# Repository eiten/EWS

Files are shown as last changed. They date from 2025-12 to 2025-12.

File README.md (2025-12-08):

# 🔌 Universal Voron Power & CAN HAT (EWS)

> 🌍 **Languages:** [English](README.md) | [Deutsch](README.de.md)

A universal interface board (HAT) for Raspberry Pi 4/5 and Radxa Rock 5B designed for use in Voron 3D printers. Provides powerful 5V supply (8A), CAN-Bus interface (USB-Bridge or Native), and USB hub.

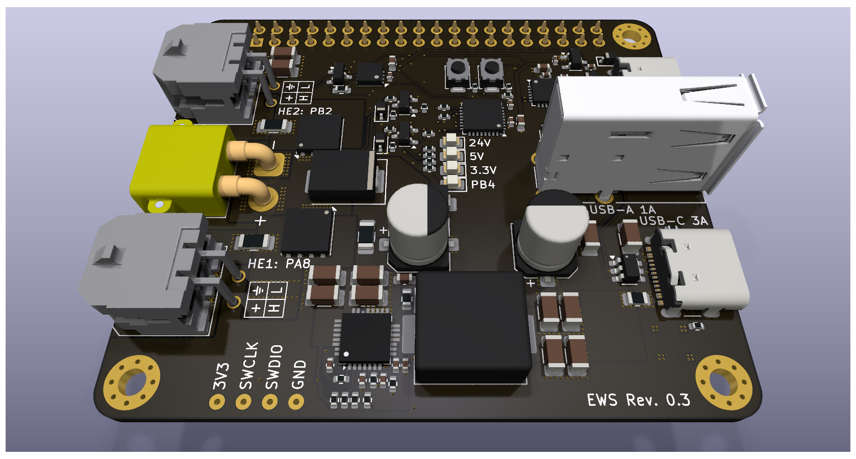
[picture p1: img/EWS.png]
Universal Voron Power & CAN HAT


## 📚 Contents

<!-- @import "[TOC]" {cmd="toc" depthFrom=1 depthTo=6 orderedList=false} -->

<!-- code_chunk_output -->

- [🔌 Universal Voron Power & CAN HAT (EWS)](#-universal-voron-power--can-hat-ews)
  - [📚 Contents](#-contents)
  - [🎯 About EWS](#-about-ews)
  - [🚨 Problems Addressed](#-problems-addressed)
  - [✨ Features](#-features)
    - [🔋 Power Supply (24V Input)](#-power-supply-24v-input)
    - [⚡ DC/DC Converter (5V Output)](#-dcdc-converter-5v-output)
    - [🔌 Logic Power Supply (Power Path)](#-logic-power-supply-power-path)
    - [💻 MCU & CAN Interface](#-mcu--can-interface)
    - [📡 USB Hub](#-usb-hub)
  - [📋 Klipper Configuration](#-klipper-configuration)
    - [Basic MCU Setup](#basic-mcu-setup)
  - [🔌 Pinout & Connector Assignment](#-pinout--connector-assignment)
    - [Power Input](#power-input)
    - [CAN-Bus Ports](#can-bus-ports)
    - [USB Ports](#usb-ports)
  - [🛠️ PCB Specifications](#️-pcb-specifications)
  - [⚠️ Manufacturing Recommendations](#️-manufacturing-recommendations)
    - [PCB Manufacturing](#pcb-manufacturing)
    - [Assembly Notes](#assembly-notes)
    - [Component Sourcing](#component-sourcing)
  - [🛠️ Technical Specifications](#️-technical-specifications)
  - [📚 Additional Resources](#-additional-resources)
  - [📝 Changelog](#-changelog)
  - [License](#license)

<!-- /code_chunk_output -->

## 🎯 About EWS

**EWS** stands for "Eierlegende Wollmilchsau" (German for "egg-laying woolly milk pig") - a humorous term for a universal solution that does everything. This HAT lives up to its nickname by combining multiple essential functions for Voron 3D printer control systems in a single, compact board.

The board addresses common pain points in Voron builds by providing robust power distribution, reliable CAN communication, and convenient USB connectivity while maintaining compatibility with both Raspberry Pi and Radxa Rock 5B single-board computers.

## 🚨 Problems Addressed

This board was designed to solve multiple critical issues commonly encountered in high-performance 3D printer setups:

### ⚡ **Power & Supply Issues**
- **Unstable SBC power supply** - Many setups suffer from voltage drops and power instability
- **Separate power injection required** - USB-C touchscreens often need additional power supplies
- **Power distribution complexity** - Multiple power sources create wiring challenges

### 🔗 **CAN Communication Problems**
- **USB-CAN adapters** - Difficult to mount, unreliable connections, additional failure points
- **Controller board limitations** - Using Spider/Octopus as CAN bridge often has built-in termination resistors
- **CAN topology conflicts** - Can't run both CAN toolheads and ADXL boards simultaneously on many controller boards
- **Native CAN unavailable** - Most SBC setups lack proper native CAN interface utilization

### 🔥 **Safety Concerns**
- **Fire hazard from thermal runaway** - No way to disconnect toolhead power during emergencies
- **Uncontrolled power delivery** - Toolheads remain powered even during faults
- **Limited emergency shutdown** - Difficult to implement comprehensive safety cutoffs

### 🔌 **Wiring & Installation**
- **Complex cable management** - CAN and 24V power start from different locations
- **Multiple connection points** - Increases failure modes and installation complexity
- **Inadequate connector standards** - Mix of different connector types creates confusion

### 🖥️ **USB & Peripheral Issues**
- **Limited USB ports** - SBCs often lack sufficient high-power USB connectivity
- **USB hub limitations** - External hubs add complexity and potential points of failure
- **Power delivery standards** - Inconsistent USB-C power delivery for modern touchscreens

## ✨ Features

### 🔋 Power Supply (24V Input)

- **Input Voltage:** 24V DC nominal
- **Connectors:** XT30PW-F (horizontal) or 5.08mm screw terminal
- **Toolhead Switching:** 2x P-Channel MOSFETs (CJAC70P06, -60V, -70A, RDSon ~8mΩ) controlled by PB2 and PA5 for toolhead power switching (safety feature if PWM-FET on toolhead fails)
- **Overvoltage Protection:** TVS diode (SMAJ26A, 26V Standoff, Unidirectional) to GND
- **Input Protection:** Distributed fusing (5A for DC/DC, 5A each for CAN ports)

### ⚡ DC/DC Converter (5V Output)

- **Controller:** MaxLinear XR76208 (Synchronous Step-Down, 8A, COT)
- **Input Fuse:** 5A SMD 1812 Slow Blow
- **Reverse Polarity Protection:** SS56 Schottky diode
- **Output Voltage:** 5.1V (set via feedback divider: R_Top=15kΩ, R_Bottom=2.0kΩ)
- **Switching Frequency:** ~600kHz (set via Ron=30kOhm)
- **Inductance:** 3.3µH Shielded (Sunlord MDA1050-3R3M, Isat ~17A)
- **Input Capacitors:** 4x 10µF 1206 ceramic + 1x 100µF electrolytic/polymer (bulk)
- **Output Capacitors:** 4x 22µF 1206 ceramic
- **Stability:** Feed-forward capacitor (Cff) 1nF parallel to upper feedback resistor
- **Soft-Start:** 100nF at SS pin (~6ms startup time)
- **Current Limit:** 5.1kΩ resistor (~10.2A limit)
- **Enable:** Voltage divider from 24V (100kΩ upper, 22kΩ lower) = ~4.3V at pin

### 🔌 Logic Power Supply (Power Path)

- **Concept:** Separation of +5V_PWR (high current for screen/webcam) and +5V_LOGIC (for MCU/Hub)
- **Diode OR-ing:** 2x Schottky diodes (1N5819WS, 1A)
  - Source 1: USB_VBUS (from Pi/PC) → Diode → +5V_LOGIC
  - Source 2: +5V_BUCK (from 8A regulator) → Diode → +5V_LOGIC
- **Purpose:** Board is USB-flashable without 24V supply, no backflow to PC
- **3.3V Generation:** LDO (XC6206) powered from +5V_LOGIC

### 🧠 MCU & CAN Interface

- **Microcontroller:** STM32G0B1KBU6 (UFQFPN-32)
- **Clocking:** Crystal-less (Internal HSI48 with Clock Recovery System CRS via USB)
- **Pi Connection:**
  - USB (PA11/PA12) to USB Hub
  - UART (PA9/PA10) to Pi Header (Pin 8/10) via jumperable connection
  - NRST to Pi GPIO 22 (via 1kΩ) + button to GND + 100nF cap
  - BOOT0 (Pin 24/PA14 shared with SWCLK) to Pi GPIO 27 (via 1kΩ) + button to 3.3V + 10kΩ pull-down
- **CAN Transceiver:** MCP2542WFD (or compatible)
- **Muxing:** Jumper selectable between STM32 (USB-CAN Bridge) and Rock/Pi Native GPIOs (Pin 3/5). For ROCK 5B/5B+, jumpers can select whether CAN comes from onboard STM32G0B1 or goes natively to Rockchip (via GPIO header Pin 3 (CAN-RX) and Pin 5 (CAN-TX))
- **Termination:** 120 Ω resistor, switchable per jumper (directly at connectors)
- **CAN Connectors:** 2x Molex Micro-Fit 3.0 (2x2)
- **Micro-Fit Pinout:** Pin 1=24V, Pin 2=GND (upper row), Pin 3=CAN_H, Pin 4=CAN_L (lower row)
- **CAN Power Protection:** 5A SMD 1812 Slow Blow per port

### 📡 USB Hub

- **Controller:** WCH CH334F (QFN-24)
- **Speed:** USB 2.0 High Speed (480 Mbit/s) with MTT
- **Clocking:** Internal (crystal-less), XI/XO pins left open
- **Supply:** V5 to +5V_LOGIC
- **Upstream:** To Raspberry Pi Header (USB loopback cable required) or USB-C input
- **Downstream Ports:**
  - STM32 (internal)
  - USB-C connector (for touchscreen)
  - USB-A connector (vertical, for webcam)

**USB Port Protection:**
- **Concept:** 100µF electrolytic tank at +5V_PWR, followed by polyfuse, followed by 22µF ceramic at connector
- **USB-C Port (Screen):**
  - Polyfuse: 4.0A hold current (hot chamber derating considered)
  - CC Lines: CC1 and CC2 each with 10kΩ resistor to VBUS (behind fuse) for 3A advertisement
  - ESD Protection: SRV05-4 TVS array
- **USB-A Port (Webcam):**
  - Polyfuse: 1.5A hold current
- **ESD Protection:** SRV05-4 TVS array

## 📋 Klipper Configuration

### Basic MCU Setup
```ini
[mcu hat]
canbus_uuid: your_uuid_here
# Alternative for USB connection:
# serial: /dev/serial/by-id/usb-katapult_stm32g0b1xx_your_id-if00

[temperature_sensor hat_mcu]
sensor_type: temperature_mcu
sensor_mcu: hat
```

## 🔌 Pinout & Connector Assignment

### Power Input
- **XT30PW-F (horizontal)** or **5.08mm Screw Terminal**
  - Pin 1: +24V
  - Pin 2: GND

### CAN-Bus Ports
- **2x Molex Micro-Fit 3.0 (2x2, THT)**
  - Pin 1: +24V (upper row, left)
  - Pin 2: GND (upper row, right)
  - Pin 3: CAN_H (lower row, left)
  - Pin 4: CAN_L (lower row, right)

### USB Ports
- **USB-C:** Touchscreen connection (5V/3A capability)
- **USB-A:** Webcam connection (vertical mount)

## 🛠️ PCB Specifications

| Parameter | Specification |
|---|---|
| **Form Factor** | Standard HAT (65mm x 56mm) |
| **Layer Stack** | 4-Layer Multilayer |
| **Layer 1 (Top)** | Signal/Power |
| **Layer 2** | GND Plane |
| **Layer 3** | 5V Power Plane |
| **Layer 4 (Bottom)** | Signal/GND |
| **Solder Mask** | Black Matte |
| **Surface Finish** | ENIG (Gold) |
| **Silkscreen** | White |
| **Mounting** | Inner mounting holes (Pi/Rock compatible) |
| **EMI Design** | Mounting holes via-stitched to GND planes (Layer 2 & Bottom), isolated from 5V plane (Layer 3) |

## ⚠️ Manufacturing Recommendations

### PCB Manufacturing
- **Copper Weight:** **2oz copper recommended** for improved thermal performance and current handling
- **Via Specifications:** Minimum 12-20 vias at DC/DC PGND for thermal management
- **Impedance Control:** 90 Ω differential for USB traces (D+/D- pairs)

### Assembly Notes
- **24V Path:** Minimum 3mm trace width on top & bottom layers for 12A total current
- **5V Distribution:** Use Layer 3 plane with solid connections (no thermals) to headers and capacitors
- **Thermal Management:** QFN GND pads connected with vias, considering bottom layer routing

### Component Sourcing
- Ensure polyfuse derating for chamber temperatures up to 60°C
- Select inductors with sufficient saturation current (>15A recommended)
- Use low-ESR capacitors for switching regulator

## 🛠️ Technical Specifications

| Parameter | Value | Unit |
|---|---|---|
| **Input Voltage** | 24 ± 2 | V |
| **5V Output Current** | 8 | A |
| **Logic Supply Current** | 2 | A |
| **CAN Baud Rate** | up to 1 | Mbit/s |
| **USB Speed** | 480 | Mbit/s |
| **Operating Temperature** | -10 to +70 | °C |
| **Dimensions** | 65 x 56 | mm |

## 📚 Additional Resources

- [Klipper Documentation](https://www.klipper3d.org/Config_Reference.html)
- [CAN-Bus Setup Guide](https://www.klipper3d.org/CANBUS.html)
- [Voron Documentation](https://docs.vorondesign.com/)
- [STM32G0 Reference Manual](https://www.st.com/resource/en/reference_manual/rm0454-stm32g0x0-advanced-armbased-32bit-mcus-stmicroelectronics.pdf)
- [Katapult Firmware Flasher](https://github.com/Arksine/katapult)

## 📝 Changelog

For detailed information about changes and updates, see [CHANGELOG.md](CHANGELOG.md).

## License

This project is licensed under the **Creative Commons Attribution-NonCommercial-ShareAlike 4.0 International License** (CC BY-NC-SA 4.0).



This means you are free to:
- **Share** — copy and redistribute the material in any medium or format
- **Adapt** — remix, transform, and build upon the material

Under the following terms:
- **Attribution** — You must give appropriate credit, provide a link to the license, and indicate if changes were made
- **NonCommercial** — You may not use the material for commercial purposes
- **ShareAlike** — If you remix, transform, or build upon the material, you must distribute your contributions under the same license

For the full license text, visit: https://creativecommons.org/licenses/by-nc-sa/4.0/

---

> **Note:** The original documentation is in German ([README.de.md](README.de.md)). This English version is a translation for international users.

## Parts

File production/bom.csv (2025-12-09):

Designator | Footprint | Quantity | Value | LCSC Part #
C201, C403 | CP_Elec_6.3x7.7 | 2 | 100u | C3151829
C202, C204, C205, C206 | 1206 | 4 | 10u | C13585
C203, C207, C211 | 0402 | 3 | 1u | C52923
C208, C210, C301, C302, C305, C401, C404 | 0402 | 7 | 100n | C307331
C209 | 0402 | 1 | 4u7 | C23733
C212 | 0603 | 1 | 220p | C1603
C213 | 0402 | 1 | 1n | C1523
C214, C215, C216, C217, C306, C307, C405, C406 | 1206 | 8 | 22u | C12891
C303, C304, C402 | 0603 | 3 | 10u | C96446
D201, D202, D203 | 0805 | 3 | YELLOW | C2296
D301 | 0805 | 1 | GREEN | C2297
D302 | SOT-23 | 1 | PESD1CAN | C907838
D401, D402 | D_SOD-323 | 2 | BZT52C15S | C19077448
D403 | D_SMC | 1 | SS56 | C24138
D404 | D_SMA | 1 | SMAJ26A | C19077543
D405, D406 | D_SOD-323 | 2 | 1N5819WS | C191023
F201 | 1206 | 1 | 3A | C163126
F401, F402 | 1206 | 2 | 5A | C163128
F403 | 0805 | 1 | 4A | C2680546
F404 | 0805 | 1 | 1.5A | C914095
HS201 | HeatSink_9x9x5 | 1 | Heatsink
J301 | PinSocket_2x20_P2.54mm_Vertical | 1 | GPIO
J401 | AMASS_XT30PW-M_1x02_P2.50mm_Horizontal | 1 | XT30 | C431092
J402, J403 | Molex_Micro-Fit_3.0_43045-0400_2x02_P3.00mm_Horizontal | 2 | MX3.0 2x2 | C122413
J404, J405 | USB_C_Receptacle_GCT_USB4105-xx-A_16P_TopMnt_Horizontal | 2 | USB-C | C2765186
J406 | USB_A_Wuerth_614004134726_Horizontal | 1 | USB-A | C18077685
L201 | L_APV_APH1050 | 1 | 3.3uH | C2847560
Q401, Q402 | AO_DFN-8-1EP_5.55x5.2mm_P1.27mm_EP4.12x4.6mm | 2 | CJAC70P06 | C2898279
Q403, Q404 | SOT-23 | 2 | AO3400A | C20917
R201 | 0402 | 1 | 22k | C25768
R202, R205 | 0402 | 2 | 2k2 | C25879
R203, R302, R305, R407, R408 | 0402 | 5 | 1k | C11702
R204 | 0402 | 1 | 100k | C25741
R206, R303, R411, R412 | 0402 | 4 | 10k | C25744
R207, R401, R402, R403, R404, R405, R406 | 0402 | 7 | 33k | C25779
R208, R409, R410 | 0402 | 3 | 5k1 | C25905
R209 | 0603 | 1 | 1R | C22936
R210 | 0402 | 1 | 15k | C25756
R211 | 0402 | 1 | 2k | C4109
R301 | 0402 | 1 | 330R | C25104
R304 | 0603 | 1 | 120R | C22787
SW301, SW302 | SW_SPST_TS-1088-xR020 | 2 | TS-1088 | C720477
U201 | SOT-23-3 | 1 | XC6206P332MR | C5446
U202 | IC_XR76208ELTR-F | 1 | XR76208 | C555356
U301 | HVSON-8-1EP_3x3mm_P0.65mm_EP1.6x2.4mm | 1 | TJA1051TK-3 | C2875699
U302 | QFN-32-1EP_5x5mm_P0.5mm_EP3.45x3.45mm | 1 | STM32G0B1KBUx | C5159549
U401 | QFN-24-1EP_4x4mm_P0.5mm_EP2.7x2.7mm_ThermalVias | 1 | CH334F | C5187527
U402, U403, U404 | SOT-23-6 | 3 | USBLC6-2SC6 | C2687116

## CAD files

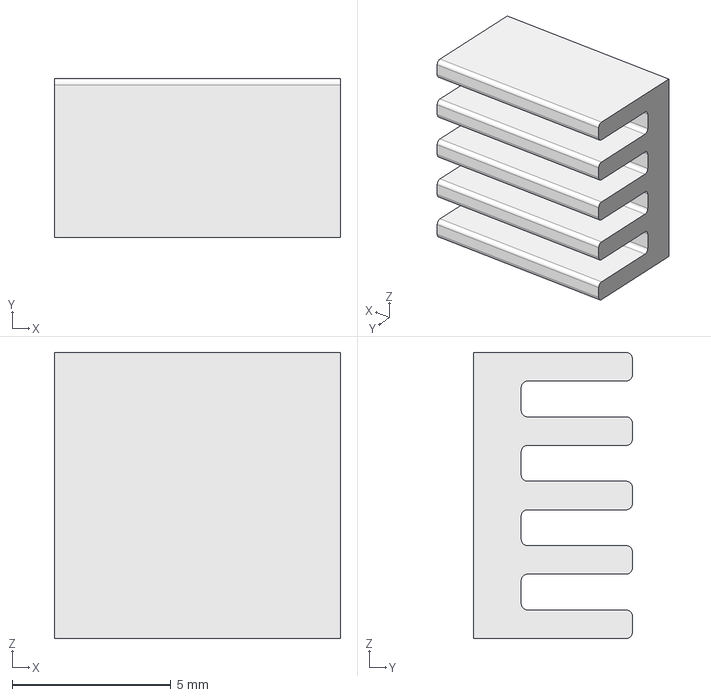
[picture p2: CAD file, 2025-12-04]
3d/9x9x5.step
9.00 x 5.00 x 9.00 mm

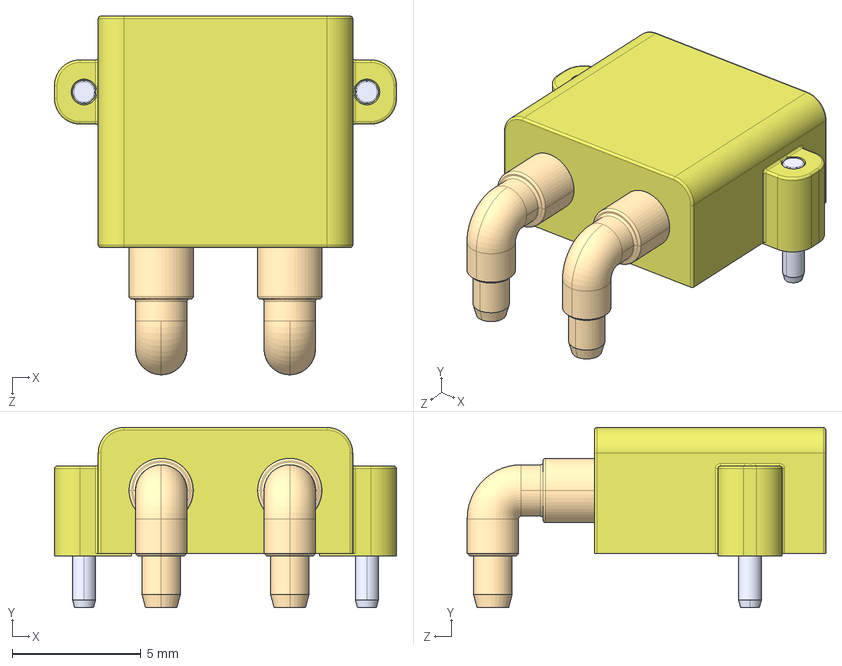
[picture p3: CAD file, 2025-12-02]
3d/XT30PW-M--3DModel-STEP-269445.STEP
13.3 x 7.00 x 14.0 mm

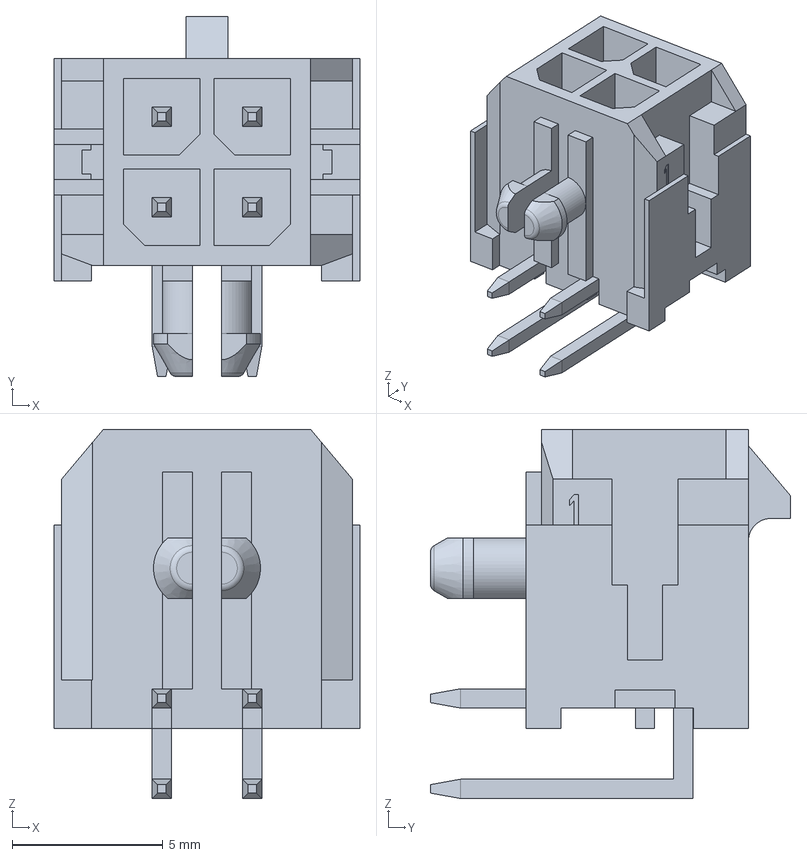
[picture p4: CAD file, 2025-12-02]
3d/430450400.stp
10.2 x 11.9 x 12.2 mm

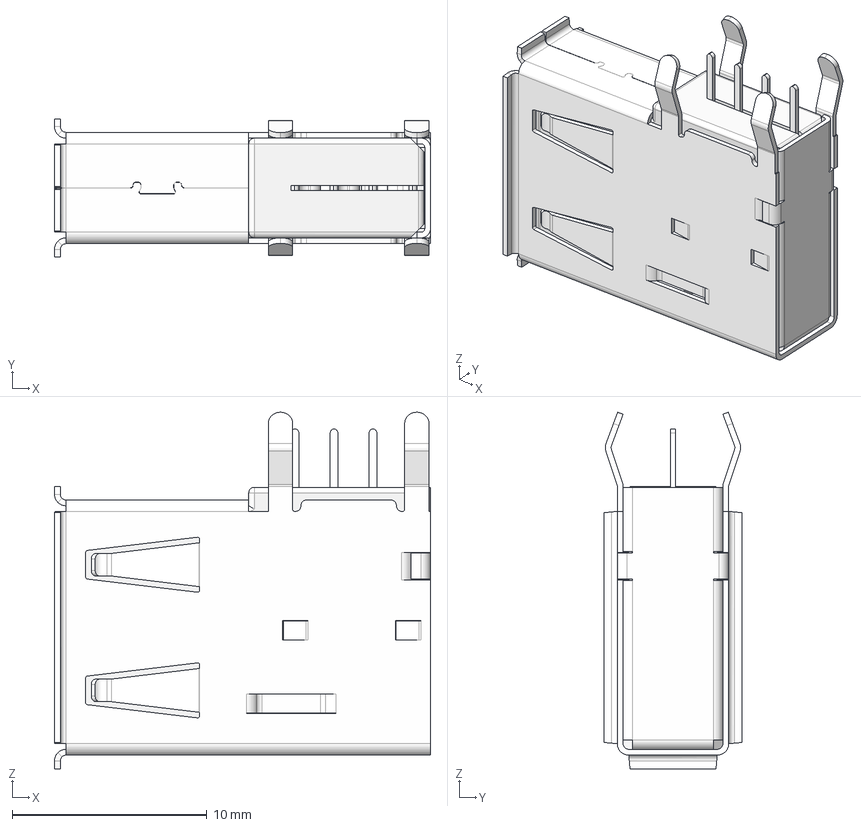
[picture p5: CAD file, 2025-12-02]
3d/614004134726.stp
19.3 x 7.10 x 18.3 mm
Blech
Blech_Deckel
Pin_4
Gehäuse_Pin
Pin_3
Pin_2
Pin_1

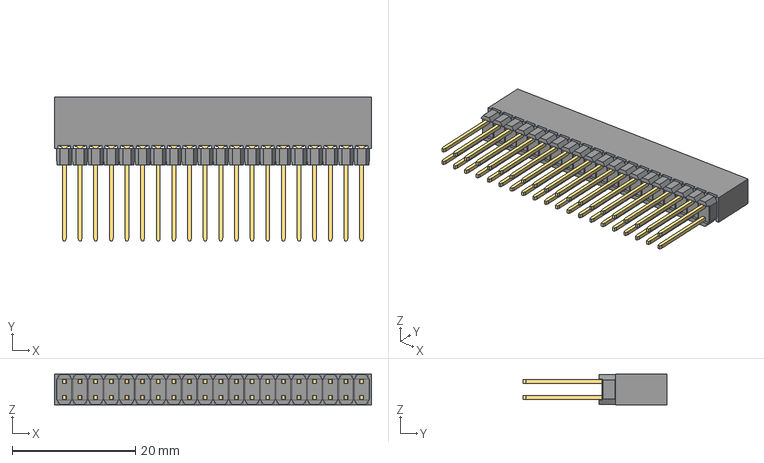
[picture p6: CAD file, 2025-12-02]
3d/m20-6102045.stp
51.5 x 23.4 x 5.00 mm

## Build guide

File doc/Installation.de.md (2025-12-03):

# 🛠️ EWS Installation Guide

> 🌍 **Sprachen:** [English](Installation.en.md) | [Deutsch](Installation.de.md)

Ein umfassender Leitfaden zur Installation des Device Tree Overlays und der Kernelmodule für das Universal Voron Power & CAN HAT (EWS).

## 📚 Inhaltsverzeichnis

- [🛠️ EWS Installation Guide](#️-ews-installation-guide)
  - [📚 Inhaltsverzeichnis](#-inhaltsverzeichnis)
  - [🏔️ Radxa Rock OS](#️-radxa-rock-os)
    - [🔍 Kernel-Treiber Diagnose](#-kernel-treiber-diagnose)
    - [📄 Device Tree Setup (DTS)](#-device-tree-setup-dts)
  - [⚠️ Wichtige Hinweise](#️-wichtige-hinweise)

## 🏔️ Radxa Rock OS

Beim Rock OS variiert die CAN-Unterstützung von Version zu Version. Eine sorgfältige Diagnose ist daher vor der Installation erforderlich.

### 🔍 Kernel-Treiber Diagnose

#### Schritt 1: Verfügbare Module prüfen
Zuerst überprüfen wir, ob die erforderlichen Kernelmodule vorhanden sind:

```bash
find /lib/modules/$(uname -r)/kernel/drivers/net/can -name "*.ko*"
```

Sind in der Liste Dateien mit Namen enthalten, die `rockchip_canfd` oder `m_can` enthalten, sind die Module vorhanden und alles sollte funktionieren.

#### Schritt 2: Kernel-Konfiguration überprüfen
Falls keine Module gefunden wurden, prüfen wir die Kernel-Konfiguration:

```bash
grep -E "CONFIG_CAN_ROCKCHIP|CONFIG_CAN_FD" /boot/config-$(uname -r)
```

#### 🚦 Diagnose-Ergebnisse

##### ✅ Fall A: `CONFIG_CAN_ROCKCHIP=y`
- **Status:** ✅ OK
- **Bedeutung:** Der Treiber ist fest im Kernel integriert
- **Hinweis:** Erscheint NICHT unter `lsmod` und hat keine `.ko` Datei
- **Aktion:** Das Overlay reicht zur Aktivierung

##### ⚠️ Fall B: `CONFIG_CAN_ROCKCHIP=m`
- **Status:** ⚠️ Prüfung erforderlich
- **Bedeutung:** Der Treiber ist ein ladbares Modul
- **Prüfung:** Modul-Datei suchen:
  ```bash
  find /lib/modules/$(uname -r) -name "rockchip_canfd.ko*"
  ```
- **Falls Datei fehlt:** Kernel-Pakete reinstallieren:
  ```bash
  sudo apt install --reinstall linux-image-rk3588*
  ```

##### ❌ Fall C: `# CONFIG_CAN_ROCKCHIP is not set`
- **Status:** ❌ KRITISCHER FEHLER
- **Symptom:** Ausgabe enthält `# CONFIG_CAN_ROCKCHIP is not set` und meist auch `# CONFIG_CAN_M_CAN is not set`
- **Bedeutung:** Kernel wurde ohne CAN-Controller-Unterstützung kompiliert
- **Problem:** Der Treiber fehlt komplett
- **DKMS-Option:** ⚠️ Praktisch unmöglich bei SoC-internen Treibern
- **Lösung:** 🔄 Zwingender Wechsel des Betriebssystems/Kernels (z.B. Armbian Vendor Kernel)

### 📄 Device Tree Setup (DTS)

Nach erfolgreicher Kernel-Diagnose kann das CAN-Overlay installiert werden:

#### Installation über Radxa Setup-Tool

1. **📁 Verzeichnis wechseln**
   ```bash
   cd dts
   ```

2. **🛠️ Radxa Setup starten**
   ```bash
   sudo rsetup
   ```

3. **🧭 Navigation im Setup-Menü**
   - Navigiere zu `Overlays` ➜ `Install 3rd party overlay`

4. **📋 Overlay auswählen**
   - Wähle `rk3588-can1-m1.dts` aus der Liste

5. **🔄 System neustarten**
   ```bash
   sudo reboot
   ```

#### ✅ Installation verifizieren

Nach dem Neustart sollte die CAN-Schnittstelle verfügbar sein:

```bash
ip link show can1
```

**Erwartete Ausgabe:**
```
3: can1: <NOARP> mtu 72 qdisc noop state DOWN mode DEFAULT group default qlen 10
    link/can
```

## ⚠️ Wichtige Hinweise

- 🔧 **Jumper-Einstellungen:** Stelle sicher, dass alle Jumper auf dem EWS-Board korrekt gesetzt sind
- 🚨 **Neustart erforderlich:** Das System muss nach der Overlay-Installation neu gestartet werden
- 📋 **Interface-Name:** Die CAN-Schnittstelle wird als `can1` im System verfügbar sein
- 🔌 **Verkabelung:** Überprüfe alle Verbindungen vor der ersten Inbetriebnahme
- 🏔️ **OS-Kompatibilität:** Diese Anleitung bezieht sich speziell auf Radxa Rock OS

---

> **💡 Tipp:** Bei persistenten Problemen empfiehlt sich der Wechsel zu Armbian mit Vendor Kernel für bessere CAN-Unterstützung.

> **Hinweis:** Dies ist die Originaldokumentation in deutscher Sprache. Eine englische Übersetzung finden Sie in [Installation.en.md](Installation.en.md).

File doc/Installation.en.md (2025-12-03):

# 🛠️ EWS Installation Guide

> 🌍 **Languages:** [English](Installation.en.md) | [Deutsch](Installation.de.md)

A comprehensive guide for installing the Device Tree Overlay and kernel modules for the Universal Voron Power & CAN HAT (EWS).

## 📚 Table of Contents

- [🛠️ EWS Installation Guide](#️-ews-installation-guide)
  - [📚 Table of Contents](#-table-of-contents)
  - [🏔️ Radxa Rock OS](#️-radxa-rock-os)
    - [🔍 Kernel Driver Diagnosis](#-kernel-driver-diagnosis)
    - [📄 Device Tree Setup (DTS)](#-device-tree-setup-dts)
  - [⚠️ Important Notes](#️-important-notes)

## 🏔️ Radxa Rock OS

CAN support in Rock OS varies from version to version. Careful diagnosis is therefore required before installation.

### 🔍 Kernel Driver Diagnosis

#### Step 1: Check Available Modules
First, we check if the required kernel modules are present:

```bash
find /lib/modules/$(uname -r)/kernel/drivers/net/can -name "*.ko*"
```

If the list contains files with names that include `rockchip_canfd` or `m_can`, the modules are present and everything should work.

#### Step 2: Check Kernel Configuration
If no modules were found, we check the kernel configuration:

```bash
grep -E "CONFIG_CAN_ROCKCHIP|CONFIG_CAN_FD" /boot/config-$(uname -r)
```

#### 🚦 Diagnosis Results

##### ✅ Case A: `CONFIG_CAN_ROCKCHIP=y`
- **Status:** ✅ OK
- **Meaning:** The driver is built into the kernel
- **Note:** Does NOT appear under `lsmod` and has no `.ko` file
- **Action:** The overlay is sufficient for activation

##### ⚠️ Case B: `CONFIG_CAN_ROCKCHIP=m`
- **Status:** ⚠️ Check required
- **Meaning:** The driver is a loadable module
- **Check:** Search for module file:
  ```bash
  find /lib/modules/$(uname -r) -name "rockchip_canfd.ko*"
  ```
- **If file missing:** Reinstall kernel packages:
  ```bash
  sudo apt install --reinstall linux-image-rk3588*
  ```

##### ❌ Case C: `# CONFIG_CAN_ROCKCHIP is not set`
- **Status:** ❌ CRITICAL ERROR
- **Symptom:** Output contains `# CONFIG_CAN_ROCKCHIP is not set` and usually also `# CONFIG_CAN_M_CAN is not set`
- **Meaning:** Kernel was compiled without CAN controller support
- **Problem:** The driver is completely missing
- **DKMS Option:** ⚠️ Practically impossible with SoC-internal drivers
- **Solution:** 🔄 Mandatory change of operating system/kernel (e.g. Armbian Vendor Kernel)

### 📄 Device Tree Setup (DTS)

After successful kernel diagnosis, the CAN overlay can be installed:

#### Installation via Radxa Setup Tool

1. **📁 Change Directory**
   ```bash
   cd dts
   ```

2. **🛠️ Start Radxa Setup**
   ```bash
   sudo rsetup
   ```

3. **🧭 Navigation in Setup Menu**
   - Navigate to `Overlays` ➜ `Install 3rd party overlay`

4. **📋 Select Overlay**
   - Choose `rk3588-can1-m1.dts` from the list

5. **🔄 Restart System**
   ```bash
   sudo reboot
   ```

#### ✅ Verify Installation

After reboot, the CAN interface should be available:

```bash
ip link show can1
```

**Expected Output:**
```
3: can1: <NOARP> mtu 72 qdisc noop state DOWN mode DEFAULT group default qlen 10
    link/can
```

## ⚠️ Important Notes

- 🔧 **Jumper Settings:** Ensure all jumpers on the EWS board are set correctly
- 🚨 **Reboot Required:** The system must be restarted after overlay installation
- 📋 **Interface Name:** The CAN interface will be available as `can1` in the system
- 🔌 **Wiring:** Check all connections before first operation
- 🏔️ **OS Compatibility:** This guide specifically refers to Radxa Rock OS

---

> **💡 Tip:** For persistent problems, switching to Armbian with Vendor Kernel is recommended for better CAN support.

> **Note:** The original documentation is in German ([Installation.de.md](Installation.de.md)). This English version is a translation for international users.

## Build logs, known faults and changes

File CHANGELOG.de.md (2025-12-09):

# Changelog

> 🌍 **Sprachen:** [English](CHANGELOG.md) | [Deutsch](CHANGELOG.de.md)

Alle wichtigen Änderungen an diesem Projekt werden in dieser Datei dokumentiert.

Das Format basiert auf [Keep a Changelog](https://keepachangelog.com/de/1.0.0/),
und dieses Projekt folgt [Semantic Versioning](https://semver.org/lang/de/).

## [Unreleased]

### Geändert
- **Produktion:** Testpunkte TP202/TP203 von Stückliste ausgeschlossen
- **JLCPCB Optimierung:** Rotations-Offsets für automatische Bestückung angepasst
  - U202/U301: FT Rotation Offset 270°
  - U401: FT Rotation Offset 180°

### Technische Details
- **Fertigungseffizienz:** Optimierte Bauteil-Orientierung reduziert Produktionszeit

## [Rev. 0.3] - 2025-12-09

### Hinzugefügt
- **CAN-Transceiver:** 10µF Kondensator C304 für verbesserte Stabilität der CAN-Kommunikation
- **PCB Layout:** QR Code Platzhalter für Seriennummer auf der Platine

### Technische Details
- **Verbesserte Signal-Integrität:** Zusätzliche Filterung am CAN-Transceiver für stabilere Datenübertragung
- **Rückverfolgbarkeit:** QR Code ermöglicht eindeutige Identifikation und Dokumentation

## [Rev. 0.2] - 2025-12-08

### Verbesserungen
- **Schaltplan:** Aufgeräumt und strukturiert (Dank an "shx")
- **CAN-Transceiver:** Silent Pin auf GND gelegt für bessere Stabilität (Dank an "shx")

### Hinzugefügt
- **Status-LEDs:** 
  - Gelbe LEDs für 24V, 5V und 3.3V Spannungsanzeige
  - Grüne LED am Mikrocontroller (Pin PB4)
- **Solder Jumper:** Ersatz der Standard-Jumper durch Solder Jumper auf der Unterseite
- **PFET-Steuerung:** Jumper für Ausgangs-PFETs hinzugefügt - ermöglicht Dauer-Ein ohne Firmware
- **Testpunkte:** Robuste Testpunkte für 5V und GND für Lasttests eingefügt
- **Heatsink:** Optionaler Heatsink für DC/DC-Wandler auf der Unterseite
- **MCU-Kondensator:** 10µF Kondensator für Mikrocontroller an der 3.3V-Schiene

### Geändert
- **Produktion:** Alle LCSC-Bestellnummern eingefügt, Rotationen definiert, Produktionsdaten erstellt
- **PCB Layout:** 
  - Entsprechend der Schaltplanänderungen angepasst
  - Taster besser positioniert
- **BOM optimiert:**
  - 30kΩ durch Basic-Part 33kΩ ersetzt
  - 15.5kΩ am DC/DC-Feedback durch 15kΩ ersetzt → neue Ausgangsspannung: 5.1V
- **CAN-ESD-Schutz:** NUP2105L durch PESD1CAN ersetzt (bessere Eignung)
- **CAN-Abschlusswiderstand:** Bauform von 0402 auf 0603 geändert für ausreichende Leistung
- **USB-Hub:** Speisung von 5V auf 3.3V umgestellt (gemäß Datenblatt-Empfehlung)

### Technische Details
- **DC/DC-Ausgang:** Neue Spannung 5.1V statt 5.25V durch Feedback-Widerstand-Änderung
- **Verbesserte Wärmeableitung:** Optionaler Heatsink auf Unterseite
- **Stabilere CAN-Kommunikation:** Durch ESD-Schutz-Upgrade und Widerstand-Optimierung

---

> **Hinweis:** Dies ist die Originaldokumentation in deutscher Sprache. Eine englische Übersetzung finden Sie in [CHANGELOG.md](CHANGELOG.md).

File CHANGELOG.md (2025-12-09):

# Changelog

> 🌍 **Languages:** [English](CHANGELOG.md) | [Deutsch](CHANGELOG.de.md)

All notable changes to this project will be documented in this file.

The format is based on [Keep a Changelog](https://keepachangelog.com/en/1.0.0/),
and this project adheres to [Semantic Versioning](https://semver.org/).

## [Unreleased]

### Changed
- **Production:** Test points TP202/TP203 excluded from BOM
- **JLCPCB Optimization:** Rotation offsets adjusted for automated assembly
  - U202/U301: FT Rotation Offset 270°
  - U401: FT Rotation Offset 180°

### Technical Details
- **Manufacturing Efficiency:** Optimized component orientation reduces production time

## [Rev. 0.3] - 2025-12-09

### Added
- **CAN Transceiver:** 10µF capacitor C304 for improved CAN communication stability
- **PCB Layout:** QR code placeholder for serial number on the PCB

### Technical Details
- **Enhanced Signal Integrity:** Additional filtering at CAN transceiver for more stable data transmission
- **Traceability:** QR code enables unique identification and documentation

## [Rev. 0.2] - 2025-12-08

### Improvements
- **Schematic:** Cleaned up and structured (Thanks to "shx")
- **CAN Transceiver:** Silent pin connected to GND for better stability (Thanks to "shx")

### Added
- **Status LEDs:** 
  - Yellow LEDs for 24V, 5V and 3.3V voltage indication
  - Green LED on microcontroller (Pin PB4)
- **Solder Jumpers:** Replaced standard jumpers with solder jumpers on bottom side
- **PFET Control:** Added jumpers for output PFETs - enables permanent-on without firmware
- **Test Points:** Added robust test points for 5V and GND for load testing
- **Heatsink:** Optional heatsink for DC/DC converter on bottom side
- **MCU Capacitor:** 10µF capacitor for microcontroller on 3.3V rail

### Changed
- **Production:** Added all LCSC part numbers, defined rotations, created production data
- **PCB Layout:** 
  - Adjusted according to schematic changes
  - Improved button positioning
- **BOM Optimized:**
  - Replaced 30kΩ with basic part 33kΩ
  - Changed 15.5kΩ DC/DC feedback to 15kΩ → new output voltage: 5.1V
- **CAN ESD Protection:** Replaced NUP2105L with PESD1CAN (better suited)
- **CAN Termination Resistor:** Changed footprint from 0402 to 0603 for adequate power rating
- **USB Hub:** Changed supply from 5V to 3.3V (per datasheet recommendation)

### Technical Details
- **DC/DC Output:** New voltage 5.1V instead of 5.25V due to feedback resistor change
- **Improved Heat Dissipation:** Optional heatsink on bottom side
- **Stable CAN Communication:** Through ESD protection upgrade and resistor optimization

---

> **Note:** The original documentation is in German ([CHANGELOG.de.md](CHANGELOG.de.md)). This English version is a translation for international users.

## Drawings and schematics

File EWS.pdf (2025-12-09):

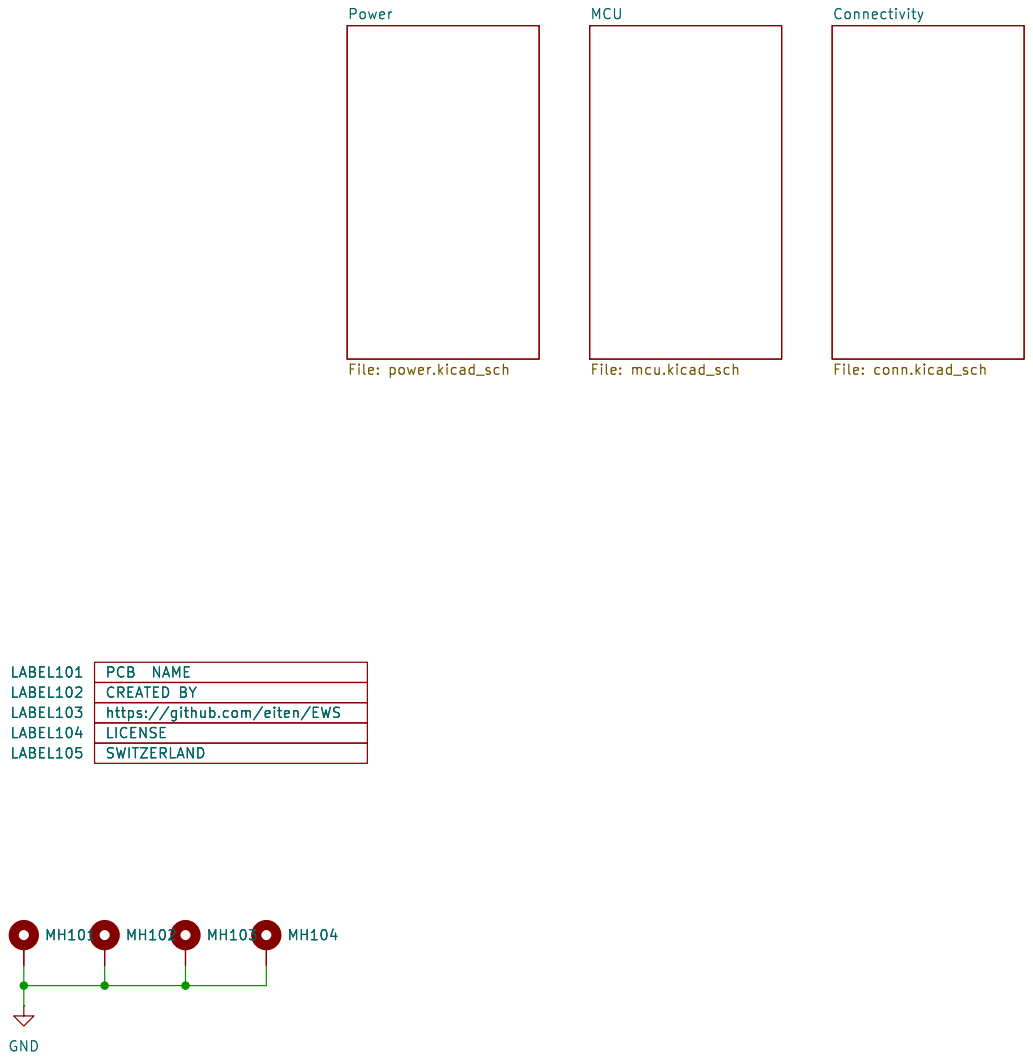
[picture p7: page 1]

Id: 1/4 Title: EWS - Power, CANbus and USB HAT for 3D Printers

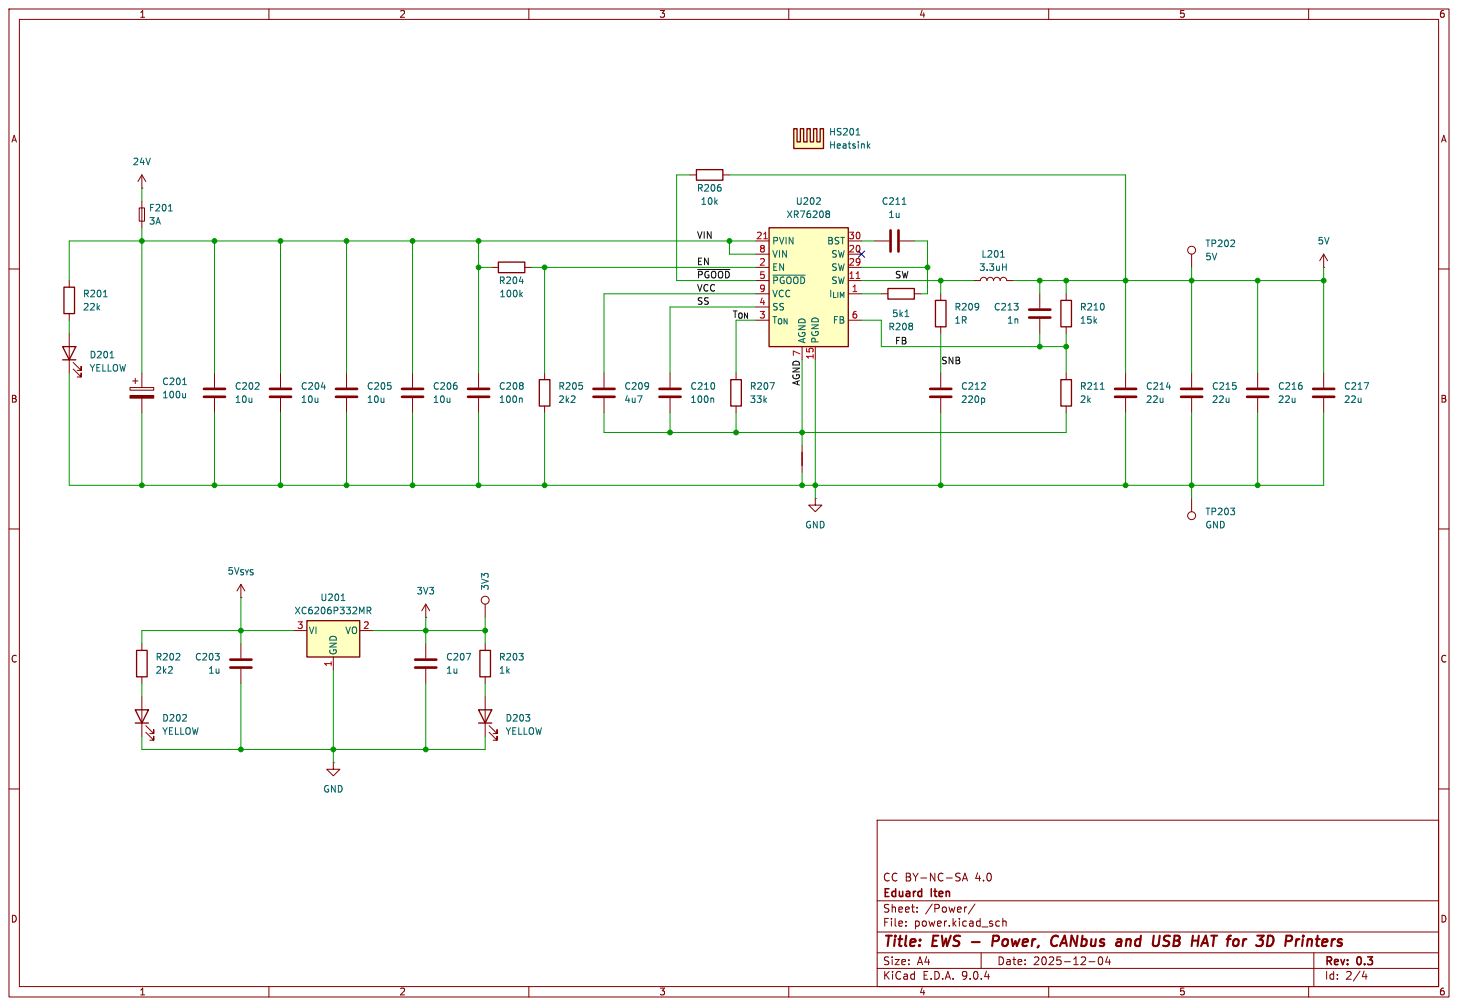
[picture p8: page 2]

7 PGND 15 BST 30 SW 20 SW 29 SW 11

Id: 2/4 Title: EWS - Power, CANbus and USB HAT for 3D Printers

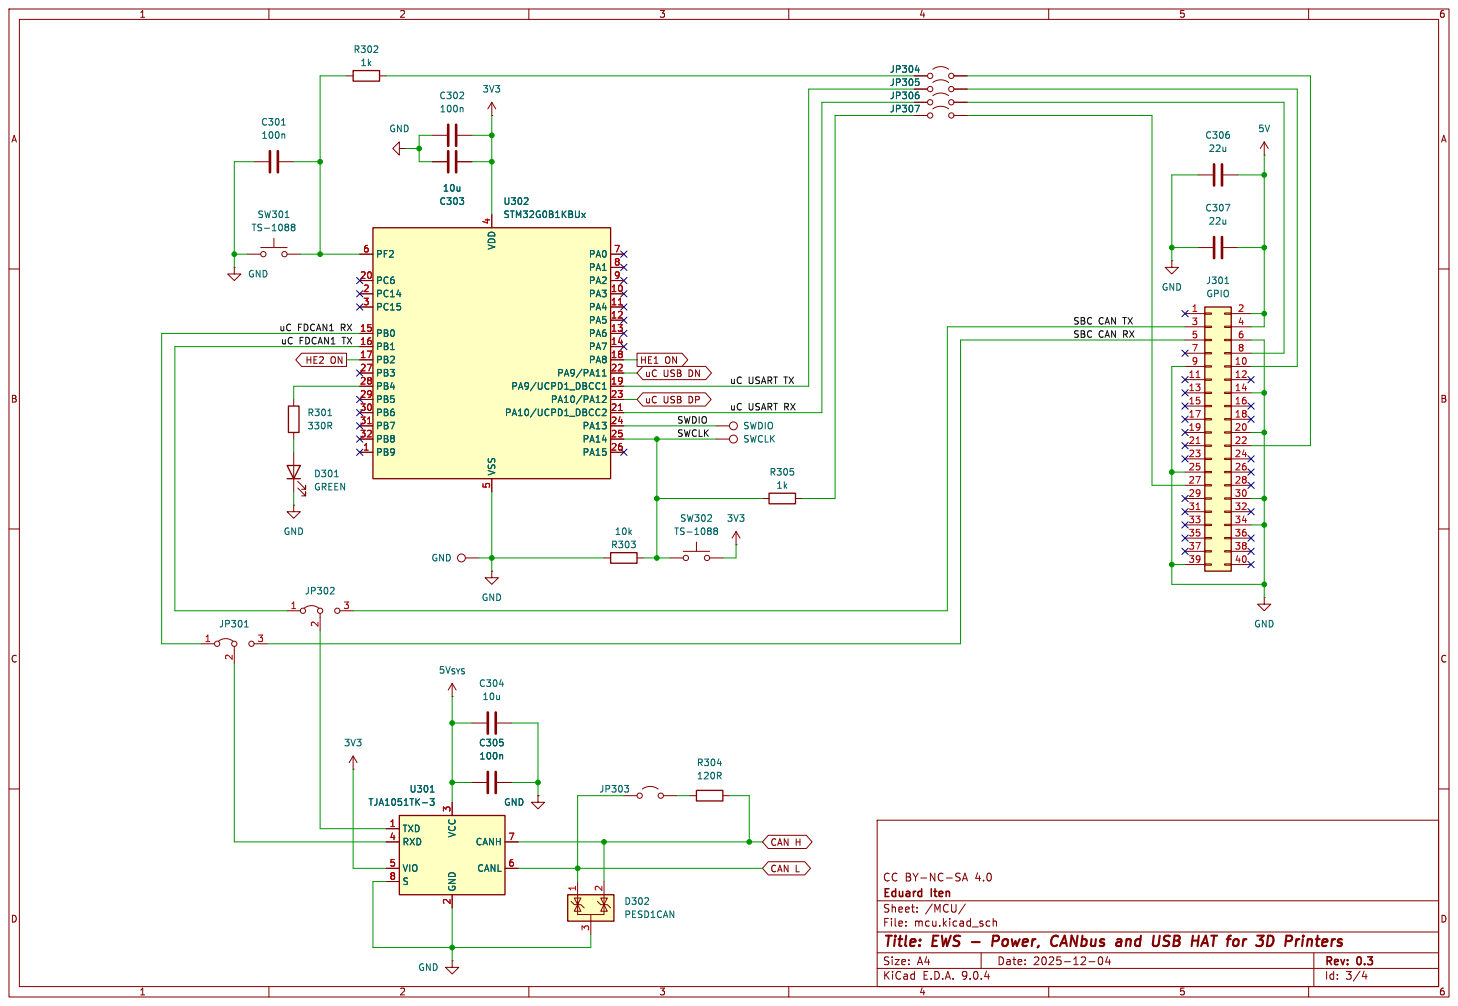
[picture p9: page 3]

Id: 3/4 Title: EWS - Power, CANbus and USB HAT for 3D Printers

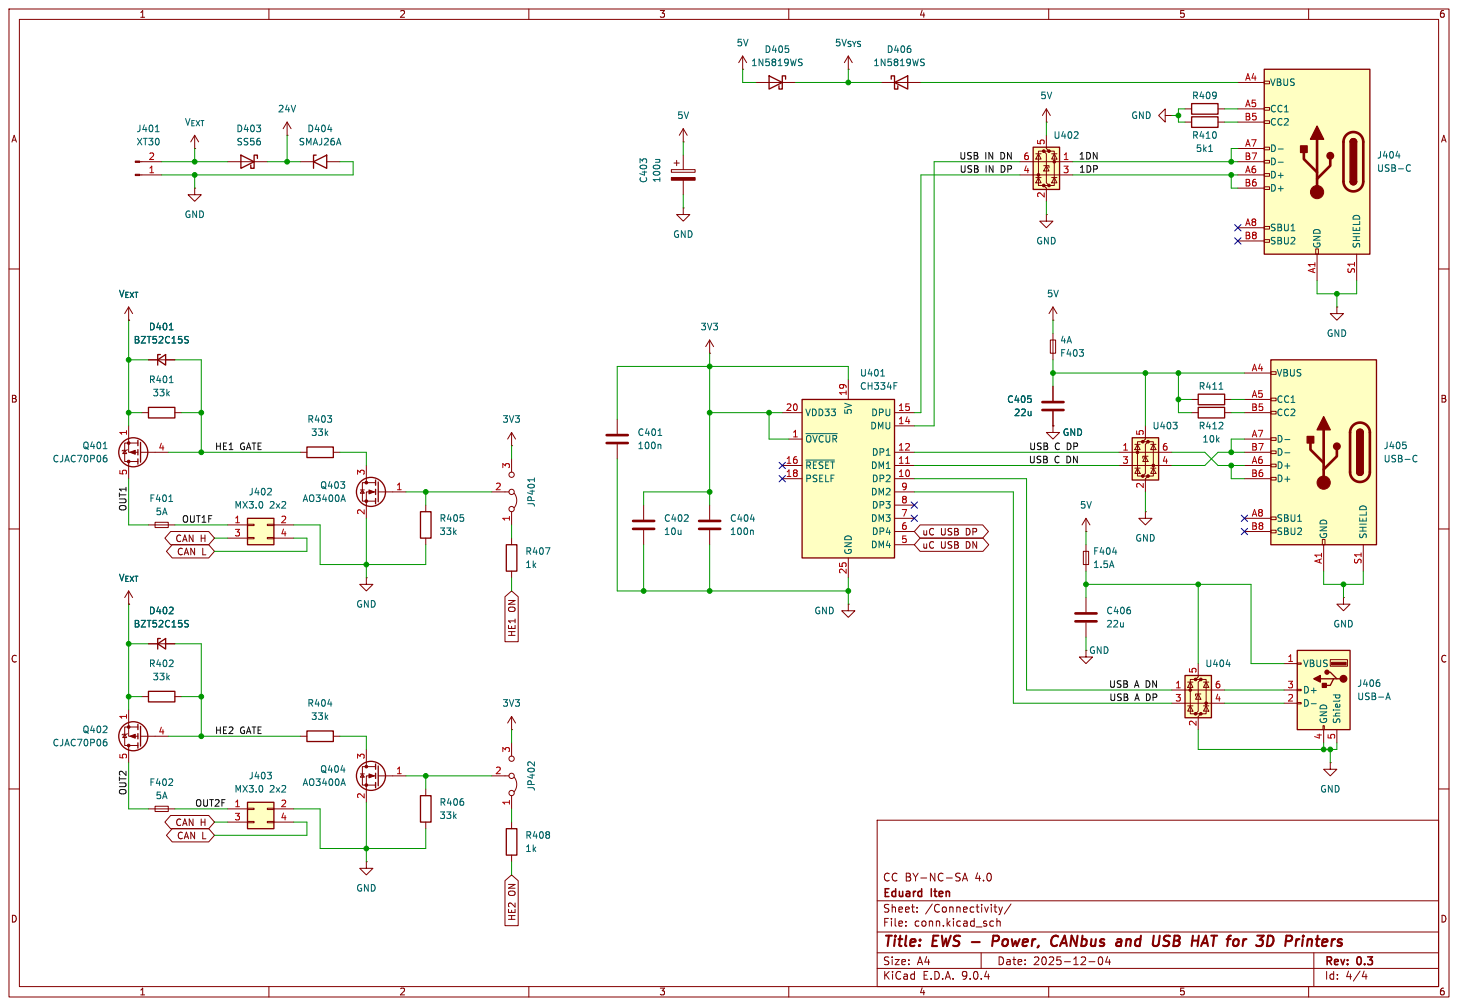
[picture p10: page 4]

5 1 Q401 CJAC70P06 VDD33 20 ~{RESET} 16 PSELF 18 ~{OVCUR} 1 5V 19 GND 25 DPU 15 DMU 14 DP1 12 DM1 11 DP2 10 DM2 9 DP3 8 DM3 7 DP4 6 DM4 5 U401 CH334F GND SHIELD S1 GND A1 VBUS A4 CC1 A5 CC2 B5 D- A7 D- B7 D+ A6 D+ B6 SBU1 A8 SBU2 B8
J403 MX3.0 2x2 CAN H
CAN L

uC USB DN HE2 ON

Id: 4/4 Title: EWS - Power, CANbus and USB HAT for 3D Printers

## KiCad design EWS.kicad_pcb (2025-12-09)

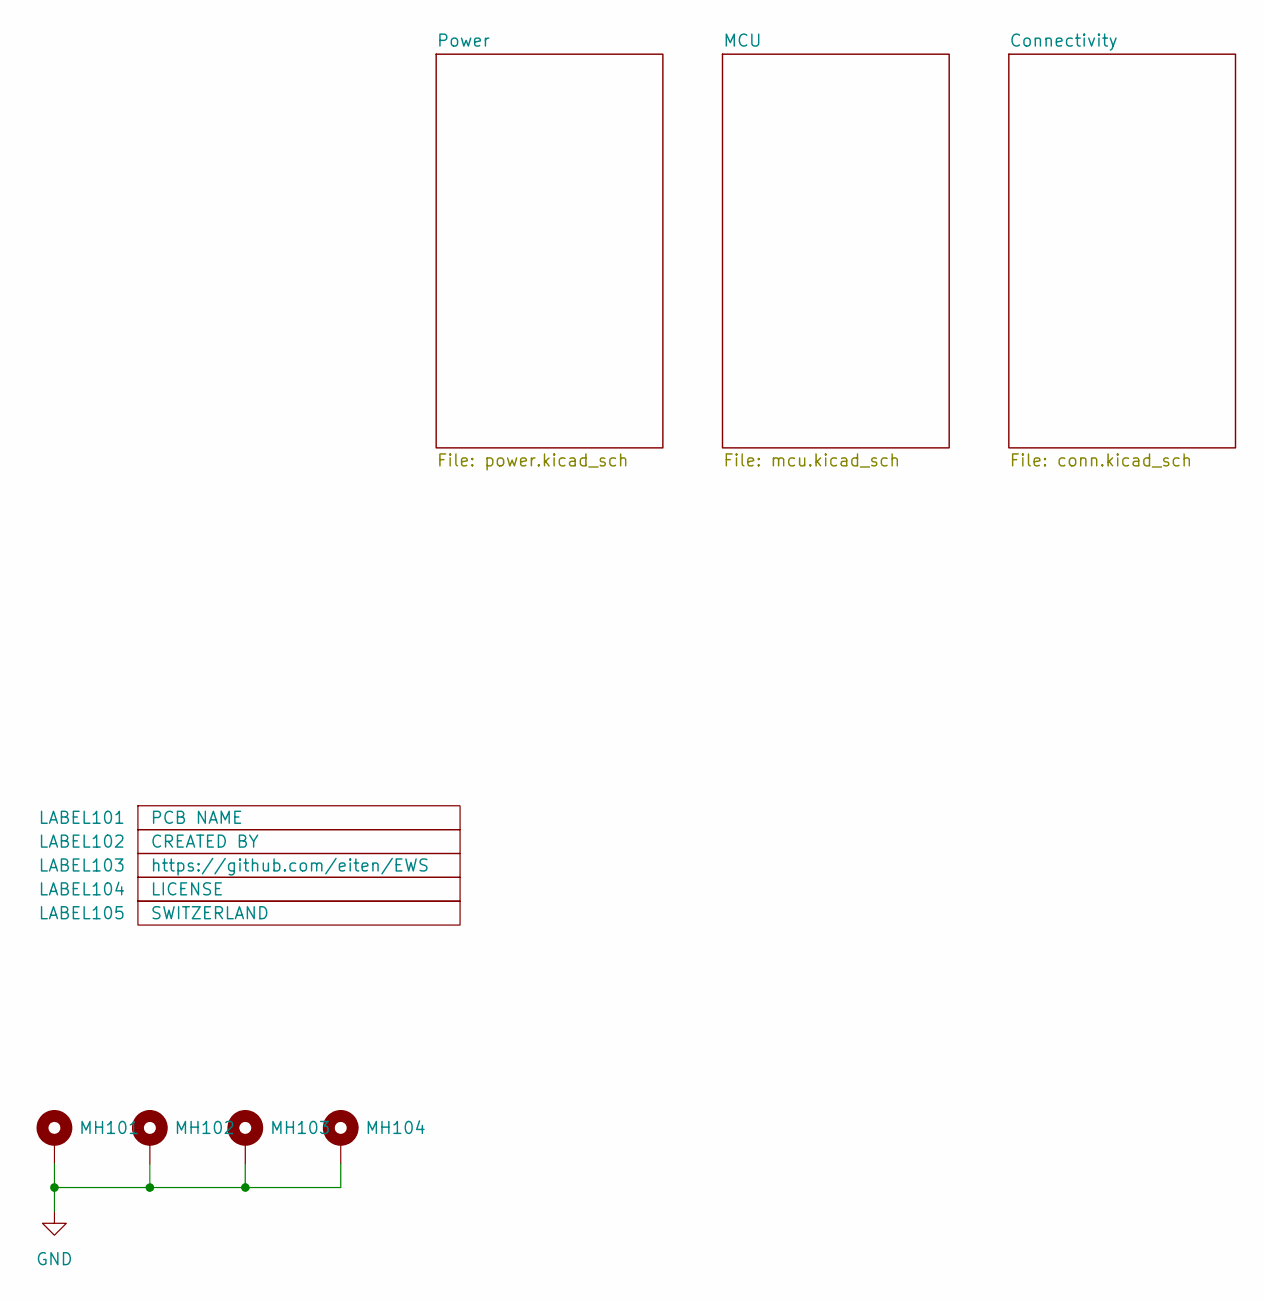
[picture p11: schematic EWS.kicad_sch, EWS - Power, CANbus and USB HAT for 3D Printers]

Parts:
LABEL101: PCB NAME; EWS Rev. 1.0
LABEL102: CREATED BY; EduardIten
LABEL103: https://github.com/eiten/EWS; http___github.com_eiten_EWS
LABEL104: LICENSE; CC_BY_NC_SA 4
LABEL105: SWITZERLAND; Switzerland
MH101, MH102, MH103, MH104: MountingHole_Pad; MountingHole_2.7mm_Pad_Via

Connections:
GND: MH101.1, MH102.1, MH103.1, MH104.1; also elsewhere on the board

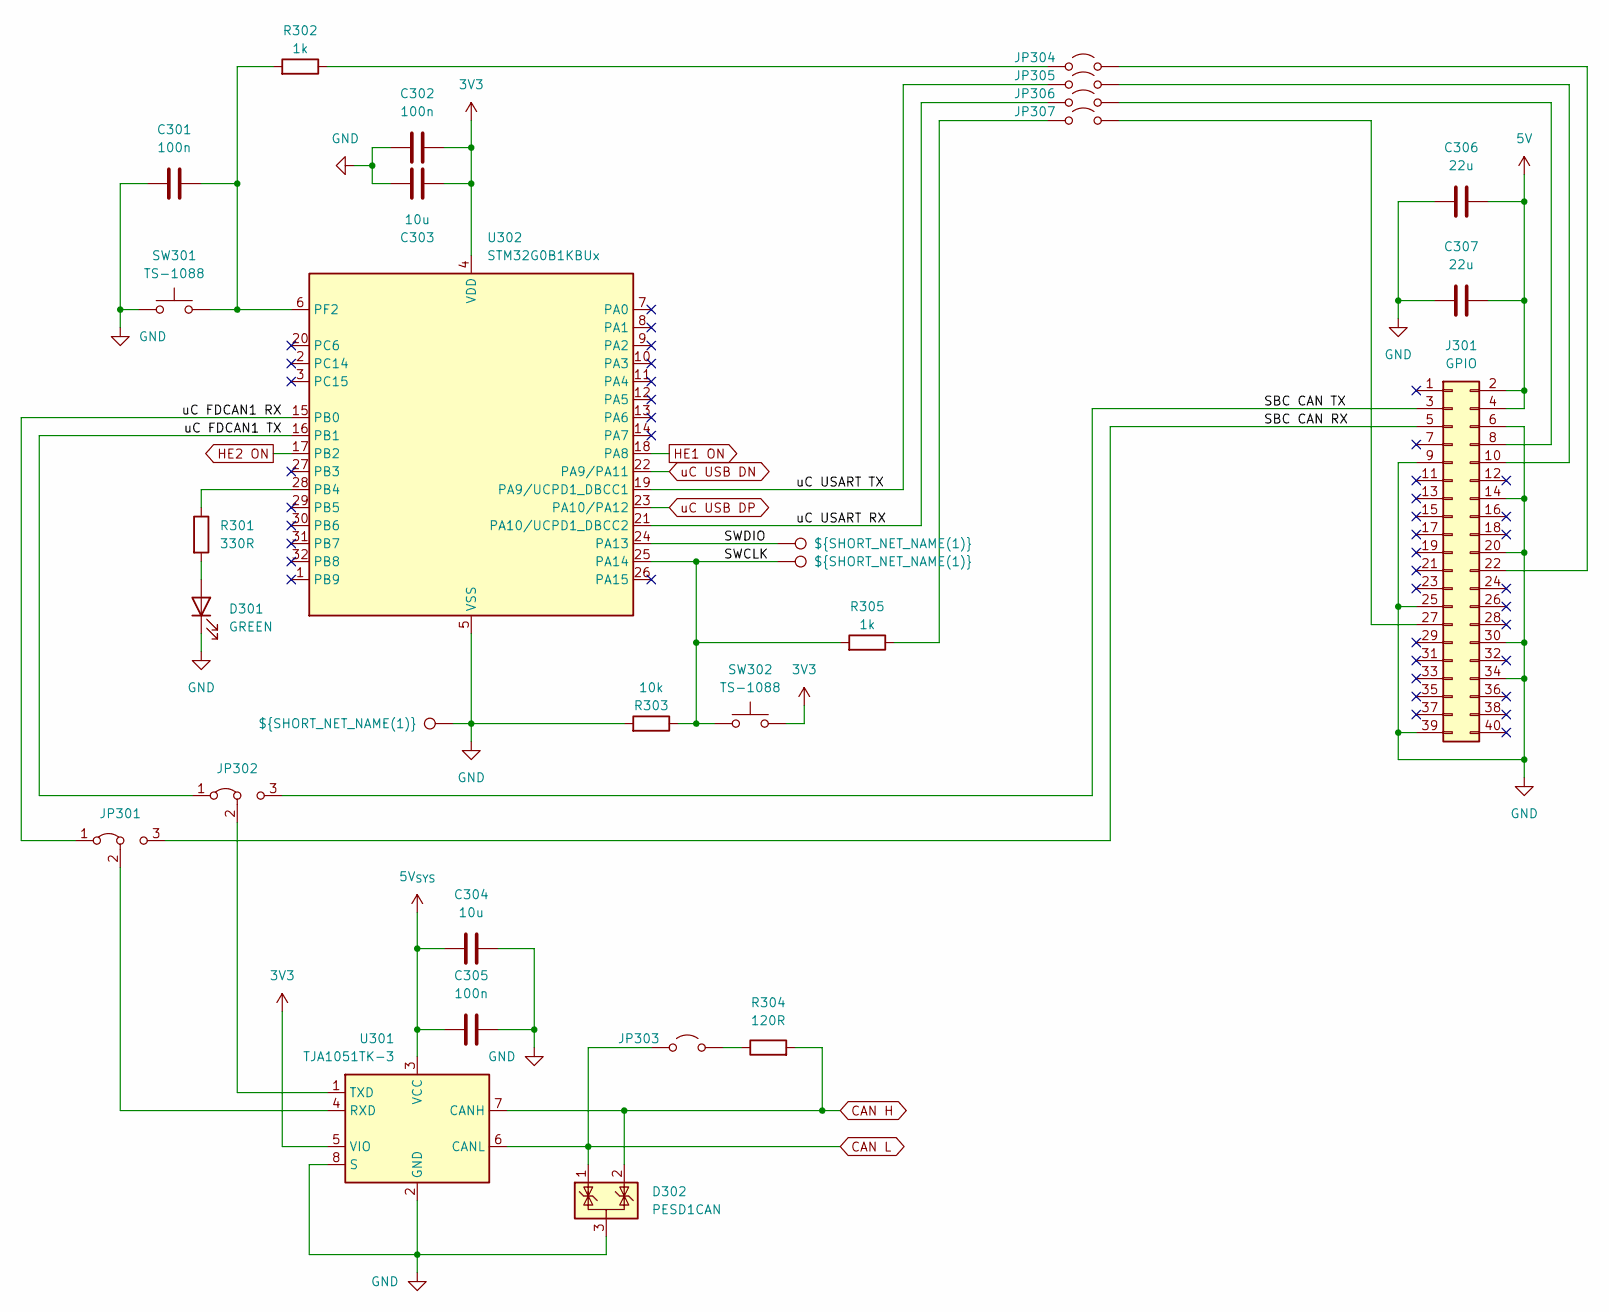
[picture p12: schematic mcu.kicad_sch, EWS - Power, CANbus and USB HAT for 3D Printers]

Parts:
C301, C302, C305: 100n; C_0402_1005Metric; Manufacturer Part # CL05B104KB54PNC; LCSC Part # C307331
C303, C304: 10u; C_0603_1608Metric; Manufacturer Part # CL10A106MA8NRNC; LCSC Part # C96446
C306, C307: 22u; C_1206_3216Metric; Manufacturer Part # CL31A226KAHNNNE; LCSC Part # C12891
D301: GREEN; LED_0805_2012Metric; Manufacturer Part # KT-0805G; LCSC Part # C2297
D302: PESD1CAN; SOT-23; Manufacturer Part # PESD1CAN; LCSC Part # C907838
J301: GPIO; PinSocket_2x20_P2.54mm_Vertical
JP301, JP302: SolderJumper-3_P1.3mm_Bridged12_RoundedPad1.0x1.5mm_custom
JP303, JP304, JP305, JP306, JP307: SolderJumper-2_P1.3mm_Open_RoundedPad1.0x1.5mm
R301: 330R; R_0402_1005Metric; Manufacturer Part # 0402WGF3300TCE; LCSC Part # C25104
R302, R305: 1k; R_0402_1005Metric; Manufacturer Part # 0402WGF1001TCE; LCSC Part # C11702
R303: 10k; R_0402_1005Metric; Manufacturer Part # 0402WGF1002TCE; LCSC Part # C25744
R304: 120R; R_0603_1608Metric; Manufacturer Part # 0603WAF1200T5E; LCSC Part # C22787
SW301, SW302: TS-1088; SW_SPST_TS-1088-xR020; Manufacturer Part # TS-1088-AR02016; LCSC Part # C720477
TP301, TP302, TP303: ${SHORT_NET_NAME(1)}; NAMED_TEST_POINT
U301: TJA1051TK-3; HVSON-8-1EP_3x3mm_P0.65mm_EP1.6x2.4mm; Manufacturer Part # TJA1051TK/3/1J; LCSC Part # C2875699
U302: STM32G0B1KBUx; QFN-32-1EP_5x5mm_P0.5mm_EP3.45x3.45mm; Manufacturer Part # STM32G0B1KBU6; LCSC Part # C5159549

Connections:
3V3: C302.2, C303.1, SW302.1, U301.5 (VIO), U302.4 (VDD); also elsewhere on the board
5V: C306.2, C307.2, J301.2, J301.4; also elsewhere on the board
5V_{SYS}: C304.1, C305.2, U301.3 (VCC); also elsewhere on the board
/MCU/SBC CAN RX: J301.5, JP301.3 (B)
/MCU/SBC CAN TX: J301.3, JP302.3 (B)
/MCU/SWCLK: R303.1, R305.2, SW302.2, TP303.1, U302.25 (PA14)
/MCU/SWDIO: TP302.1, U302.24 (PA13)
/MCU/uC FDCAN1 RX: JP301.1 (A), U302.15 (PB0)
/MCU/uC FDCAN1 TX: JP302.1 (A), U302.16 (PB1)
/MCU/uC USART RX: JP306.1 (A), U302.21 (PA10/UCPD1_DBCC2)
/MCU/uC USART TX: JP305.1 (A), U302.19 (PA9/UCPD1_DBCC1)
CAN H: D302.2 (K), R304.2, U301.7 (CANH); also elsewhere on the board
CAN L: D302.1 (K), JP303.1 (A), U301.6 (CANL); also elsewhere on the board
GND: C301.1, C302.1, C303.2, C304.2, C305.1, C306.1, C307.1, D301.1 (K), D302.3 (A), J301.6, J301.9, J301.14, J301.20, J301.25, J301.30, J301.34, J301.39, R303.2, SW301.1, TP301.1, U301.2 (GND), U301.8 (S), U301.9 (GND), U302.5 (VSS), U302.33 (VSS); also elsewhere on the board
HE1 ON: U302.18 (PA8); also elsewhere on the board
HE2 ON: U302.17 (PB2); also elsewhere on the board
unnamed: D301.2 (A), R301.2
unnamed: J301.8, JP306.2 (B)
unnamed: J301.10, JP305.2 (B)
unnamed: J301.22, JP304.2 (B)
unnamed: J301.27, JP307.2 (B)
unnamed: JP301.2 (C), U301.4 (RXD)
unnamed: JP302.2 (C), U301.1 (TXD)
unnamed: JP303.2 (B), R304.1
unnamed: JP304.1 (A), R302.1
unnamed: JP307.1 (A), R305.1
unnamed: R301.1, U302.28 (PB4)
unnamed: C301.2, R302.2, SW301.2, U302.6 (PF2)
uC USB DN: U302.22 (PA9/PA11); also elsewhere on the board
uC USB DP: U302.23 (PA10/PA12); also elsewhere on the board

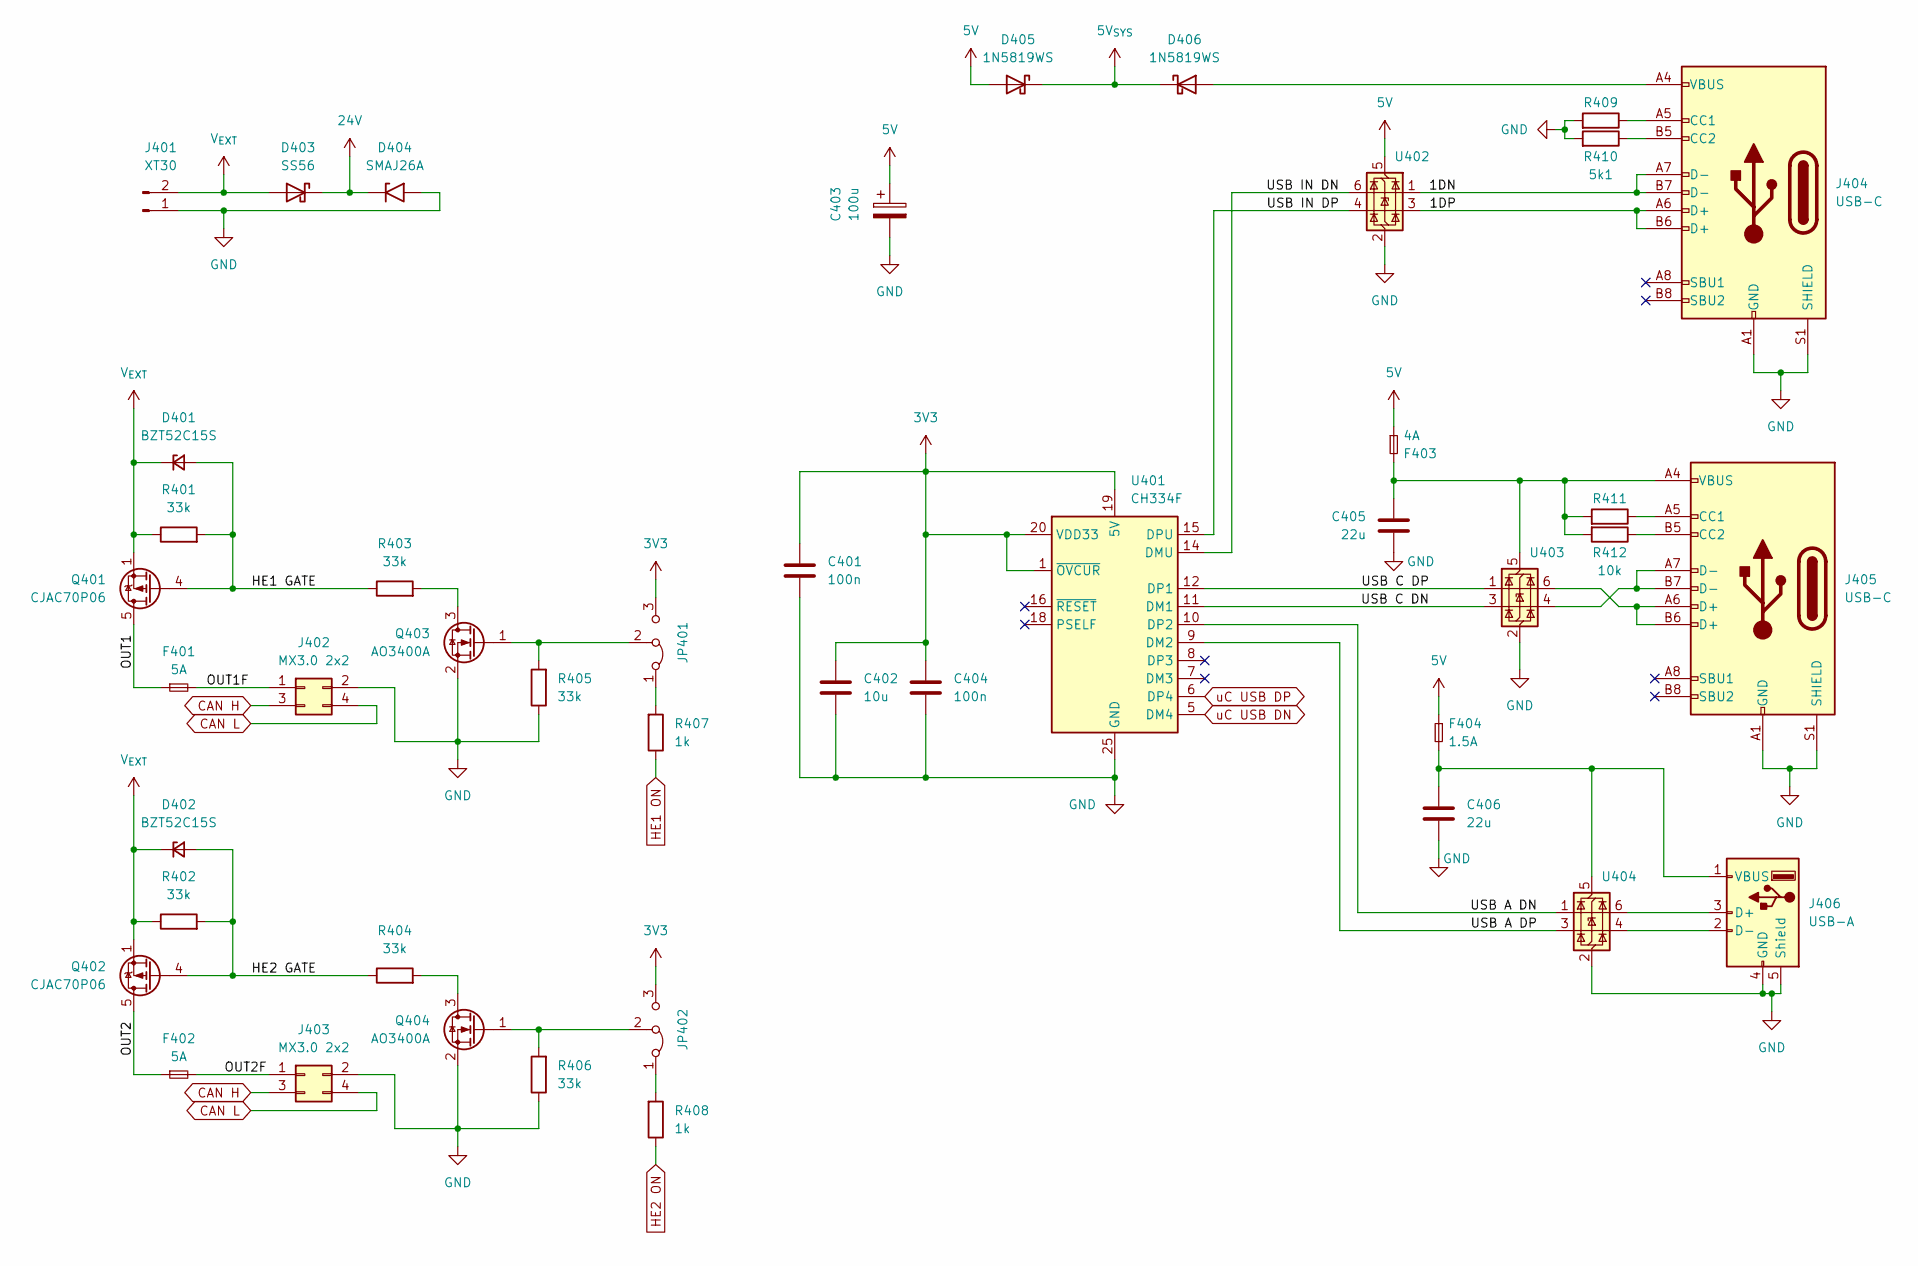
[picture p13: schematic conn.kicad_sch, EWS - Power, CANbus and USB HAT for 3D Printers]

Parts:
C401, C404: 100n; C_0402_1005Metric; Manufacturer Part # CL05B104KB54PNC; LCSC Part # C307331
C402: 10u; C_0603_1608Metric; Manufacturer Part # CL10A106MA8NRNC; LCSC Part # C96446
C403: 100u; CP_Elec_6.3x7.7; Manufacturer Part # RVT1H101M0607; LCSC Part # C3151829
C405, C406: 22u; C_1206_3216Metric; Manufacturer Part # CL31A226KAHNNNE; LCSC Part # C12891
D401, D402: BZT52C15S; D_SOD-323; Manufacturer Part # BZT52C15S; LCSC Part # C19077448
D403: SS56; D_SMC; Manufacturer Part # SS56C; LCSC Part # C24138
D404: SMAJ26A; D_SMA; Manufacturer Part # SMAJ26A; LCSC Part # C19077543
D405, D406: 1N5819WS; D_SOD-323; Manufacturer Part # 1N5819WS; LCSC Part # C191023
F401, F402: 5A; Fuse_1206_3216Metric_Pad1.42x1.75mm_HandSolder; Manufacturer Part # CFS12V3T5R0; LCSC Part # C163128
F403: 4A; Fuse_0805_2012Metric; Manufacturer Part # JK-SMD-0805-400L-12; LCSC Part # C2680546
F404: 1.5A; Fuse_0805_2012Metric; Manufacturer Part # BSMD0805L-150; LCSC Part # C914095
J401: XT30; AMASS_XT30PW-M_1x02_P2.50mm_Horizontal; Manufacturer Part # XT30PW-M30.G.Y; LCSC Part # C431092
J402, J403: MX3.0 2x2; Molex_Micro-Fit_3.0_43045-0400_2x02_P3.00mm_Horizontal; Manufacturer Part # 430450400; LCSC Part # C122413
J404, J405: USB-C; USB_C_Receptacle_GCT_USB4105-xx-A_16P_TopMnt_Horizontal; Manufacturer Part # TYPE-C 16PIN 2MD(073); LCSC Part # C2765186
J406: USB-A; USB_A_Wuerth_614004134726_Horizontal; Manufacturer Part # BX-TYPE-A-MCC4P; LCSC Part # C18077685
JP401, JP402: SolderJumper-3_P1.3mm_Bridged12_RoundedPad1.0x1.5mm_custom
Q401, Q402: CJAC70P06; AO_DFN-8-1EP_5.55x5.2mm_P1.27mm_EP4.12x4.6mm; Manufacturer Part # CJAC70P06; LCSC Part # C2898279
Q403, Q404: AO3400A; SOT-23; Manufacturer Part # AO3400A; LCSC Part # C20917
R401, R402, R403, R404, R405, R406: 33k; R_0402_1005Metric; Manufacturer Part # 0402WGF3302TCE; LCSC Part # C25779
R407, R408: 1k; R_0402_1005Metric; Manufacturer Part # 0402WGF1001TCE; LCSC Part # C11702
R409, R410: 5k1; R_0402_1005Metric; Manufacturer Part # 0402WGF5101TCE; LCSC Part # C25905
R411, R412: 10k; R_0402_1005Metric; Manufacturer Part # 0402WGF1002TCE; LCSC Part # C25744
U401: CH334F; QFN-24-1EP_4x4mm_P0.5mm_EP2.7x2.7mm_ThermalVias; Manufacturer Part # CH334F; LCSC Part # C5187527
U402, U403, U404: USBLC6-2SC6; SOT-23-6; Manufacturer Part # USBLC6-2SC6; LCSC Part # C2687116

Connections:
3V3: C401.1, C402.1, C404.1, JP401.3 (B), JP402.3 (B), U401.1 (~OVCUR), U401.19 (5V), U401.20 (VDD33); also elsewhere on the board
5V: C403.1, D405.2 (A), F403.1, F404.1, U402.5 (VBUS); also elsewhere on the board
5V_{SYS}: D405.1 (K), D406.1 (K); also elsewhere on the board
24V: D403.1 (K), D404.1 (A1); also elsewhere on the board
/Connectivity/1DN: J404.A7 (D-), J404.B7 (D-), U402.1 (I/O1)
/Connectivity/1DP: J404.A6 (D+), J404.B6 (D+), U402.3 (I/O2)
/Connectivity/HE1 GATE: D401.2 (A), Q401.4 (G), R401.2, R403.1
/Connectivity/HE2 GATE: D402.2 (A), Q402.4 (G), R402.2, R404.1
/Connectivity/OUT1: F401.1, Q401.5 (D)
/Connectivity/OUT1F: F401.2, J402.1
/Connectivity/OUT2: F402.1, Q402.5 (D)
/Connectivity/OUT2F: F402.2, J403.1
/Connectivity/USB A DN: U401.10 (DP2), U404.1 (I/O1)
/Connectivity/USB A DP: U401.9 (DM2), U404.3 (I/O2)
/Connectivity/USB C DN: U401.11 (DM1), U403.3 (I/O2)
/Connectivity/USB C DP: U401.12 (DP1), U403.1 (I/O1)
/Connectivity/USB IN DN: U401.14 (DMU), U402.6 (I/O1)
/Connectivity/USB IN DP: U401.15 (DPU), U402.4 (I/O2)
CAN H: J402.3, J403.3; also elsewhere on the board
CAN L: J402.4, J403.4; also elsewhere on the board
GND: C401.2, C402.2, C403.2, C404.2, C405.2, C406.2, D404.2 (A2), J401.1, J402.2, J403.2, J404.A1 (GND), J404.A12 (GND), J404.B1 (GND), J404.B12 (GND), J404.S1 (SHIELD), J405.A1 (GND), J405.A12 (GND), J405.B1 (GND), J405.B12 (GND), J405.S1 (SHIELD), J406.4 (GND), J406.5 (Shield), Q403.2 (S), Q404.2 (S), R405.1, R406.1, R409.2, R410.2, U401.25 (GND), U402.2 (GND), U403.2 (GND), U404.2 (GND); also elsewhere on the board
HE1 ON: R407.1; also elsewhere on the board
HE2 ON: R408.1; also elsewhere on the board
unnamed: D406.2 (A), J404.A4 (VBUS), J404.A9 (VBUS), J404.B4 (VBUS), J404.B9 (VBUS)
unnamed: J404.A5 (CC1), R409.1
unnamed: J404.B5 (CC2), R410.1
unnamed: J405.A5 (CC1), R411.1
unnamed: J405.B5 (CC2), R412.1
unnamed: J405.A6 (D+), J405.B6 (D+), U403.6 (I/O1)
unnamed: J405.A7 (D-), J405.B7 (D-), U403.4 (I/O2)
unnamed: J406.3 (D+), U404.6 (I/O1)
unnamed: J406.2 (D-), U404.4 (I/O2)
unnamed: C406.1, F404.2, J406.1 (VBUS), U404.5 (VBUS)
unnamed: JP401.1 (A), R407.2
unnamed: JP401.2 (C), Q403.1 (G), R405.2
unnamed: JP402.1 (A), R408.2
unnamed: JP402.2 (C), Q404.1 (G), R406.2
unnamed: Q403.3 (D), R403.2
unnamed: Q404.3 (D), R404.2
unnamed: C405.1, F403.2, J405.A4 (VBUS), J405.A9 (VBUS), J405.B4 (VBUS), J405.B9 (VBUS), R411.2, R412.2, U403.5 (VBUS)
V_{EXT}: D401.1 (K), D402.1 (K), D403.2 (A), J401.2, Q401.1 (S), Q401.2 (S), Q401.3 (S), Q402.1 (S), Q402.2 (S), Q402.3 (S), R401.1, R402.1
uC USB DN: U401.5 (DM4); also elsewhere on the board
uC USB DP: U401.6 (DP4); also elsewhere on the board

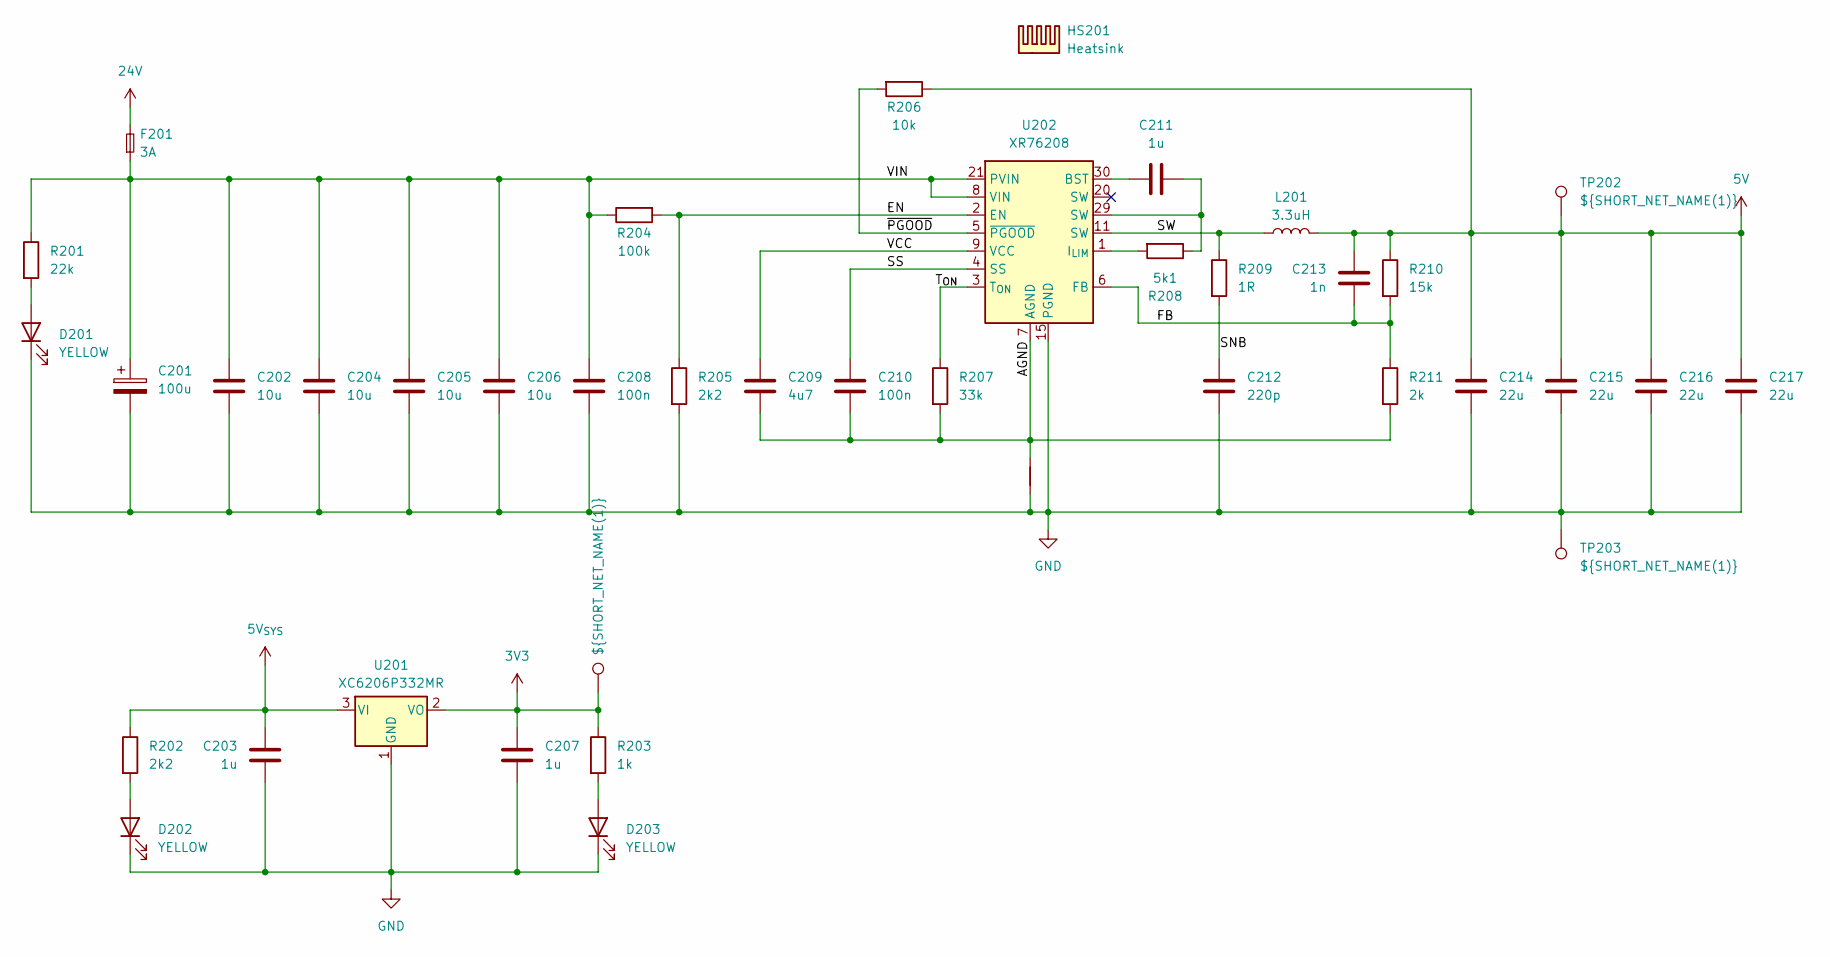
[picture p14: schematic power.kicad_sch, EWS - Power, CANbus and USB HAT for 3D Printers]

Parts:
C201: 100u; CP_Elec_6.3x7.7; Manufacturer Part # RVT1H101M0607; LCSC Part # C3151829
C202, C204, C205, C206: 10u; C_1206_3216Metric; Manufacturer Part # CL31A106KBHNNNE; LCSC Part # C13585
C203, C207, C211: 1u; C_0402_1005Metric; Manufacturer Part # CL05A105KA5NQNC; LCSC Part # C52923
C208, C210: 100n; C_0402_1005Metric; Manufacturer Part # CL05B104KB54PNC; LCSC Part # C307331
C209: 4u7; C_0402_1005Metric; Manufacturer Part # CL05A475MP5NRNC; LCSC Part # C23733
C212: 220p; C_0603_1608Metric; Manufacturer Part # CL10B221KB8NNNC; LCSC Part # C1603
C213: 1n; C_0402_1005Metric; Manufacturer Part # 0402B102K500NT; LCSC Part # C1523
C214, C215, C216, C217: 22u; C_1206_3216Metric; Manufacturer Part # CL31A226KAHNNNE; LCSC Part # C12891
D201, D202, D203: YELLOW; LED_0805_2012Metric; Manufacturer Part # KT-0805Y; LCSC Part # C2296
F201: 3A; Fuse_1206_3216Metric_Pad1.42x1.75mm_HandSolder; Manufacturer Part # CFS12V3T3R00; LCSC Part # C163126
HS201: Heatsink; HeatSink_9x9x5
L201: 3.3uH; L_APV_APH1050; Manufacturer Part # MDA1050-3R3M; LCSC Part # C2847560
NT201: NetTie_2; NetTie-2_SMD_Pad0.5mm
R201: 22k; R_0402_1005Metric; Manufacturer Part # 0402WGF2202TCE; LCSC Part # C25768
R202, R205: 2k2; R_0402_1005Metric; Manufacturer Part # 0402WGF2201TCE; LCSC Part # C25879
R203: 1k; R_0402_1005Metric; Manufacturer Part # 0402WGF1001TCE; LCSC Part # C11702
R204: 100k; R_0402_1005Metric; Manufacturer Part # 0402WGF1003TCE; LCSC Part # C25741
R206: 10k; R_0402_1005Metric; Manufacturer Part # 0402WGF1002TCE; LCSC Part # C25744
R207: 33k; R_0402_1005Metric; Manufacturer Part # 0402WGF3302TCE; LCSC Part # C25779
R208: 5k1; R_0402_1005Metric; Manufacturer Part # 0402WGF5101TCE; LCSC Part # C25905
R209: 1R; R_0603_1608Metric; Manufacturer Part # 0603WAF100KT5E; LCSC Part # C22936
R210: 15k; R_0402_1005Metric; Manufacturer Part # 0402WGF1502TCE; LCSC Part # C25756
R211: 2k; R_0402_1005Metric; Manufacturer Part # 0402WGF2001TCE; LCSC Part # C4109
TP201: ${SHORT_NET_NAME(1)}; NAMED_TEST_POINT
TP202, TP203: ${SHORT_NET_NAME(1)}; TestPoint_Pad_D3.0mm
U201: XC6206P332MR; SOT-23-3; Manufacturer Part # XC6206P332MR-G; LCSC Part # C5446
U202: XR76208; IC_XR76208ELTR-F; Manufacturer Part # XR76208ELTR-F; LCSC Part # C555356

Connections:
3V3: C207.2, R203.1, TP201.1, U201.2 (VO); also elsewhere on the board
5V: C213.1, C214.1, C215.1, C216.1, C217.1, L201.2, R206.1, R210.1, TP202.1; also elsewhere on the board
5V_{SYS}: C203.2, R202.1, U201.3 (VI); also elsewhere on the board
24V: F201.2; also elsewhere on the board
/Power/AGND: C209.2, C210.2, NT201.2, R207.2, R211.2, U202.7 (AGND), U202.10 (AGND)
/Power/EN: R204.2, R205.1, U202.2 (EN)
/Power/FB: C213.2, R210.2, R211.1, U202.6 (FB)
/Power/SNB: C212.1, R209.2
/Power/SS: C210.1, U202.4 (SS)
/Power/SW: L201.1, R209.1, U202.11 (SW), U202.12 (SW), U202.13 (SW), U202.14 (SW)
/Power/T_{ON}: R207.1, U202.3 (T_{ON})
/Power/VCC: C209.1, U202.9 (VCC)
/Power/VIN: C201.1, C202.1, C204.1, C205.1, C206.1, C208.1, F201.1, R201.1, R204.1, U202.8 (VIN), U202.21 (PVIN), U202.22 (PVIN), U202.23 (PVIN), U202.24 (PVIN), U202.25 (PVIN), U202.26 (PVIN), U202.27 (PVIN), U202.28 (PVIN)
/Power/~PGOOD: R206.2, U202.5 (~PGOOD)
GND: C201.2, C202.2, C203.1, C204.2, C205.2, C206.2, C207.1, C208.2, C212.2, C214.2, C215.2, C216.2, C217.2, D201.1 (K), D202.1 (K), D203.1 (K), NT201.1, R205.2, TP203.1, U201.1 (GND), U202.15 (PGND), U202.16 (PGND), U202.17 (PGND), U202.18 (PGND), U202.19 (PGND); also elsewhere on the board
unnamed: C211.2, R208.1, U202.29 (SW)
unnamed: D201.2 (A), R201.2
unnamed: D202.2 (A), R202.2
unnamed: D203.2 (A), R203.2
unnamed: C211.1, U202.30 (BST)
unnamed: R208.2, U202.1 (I_{LIM})

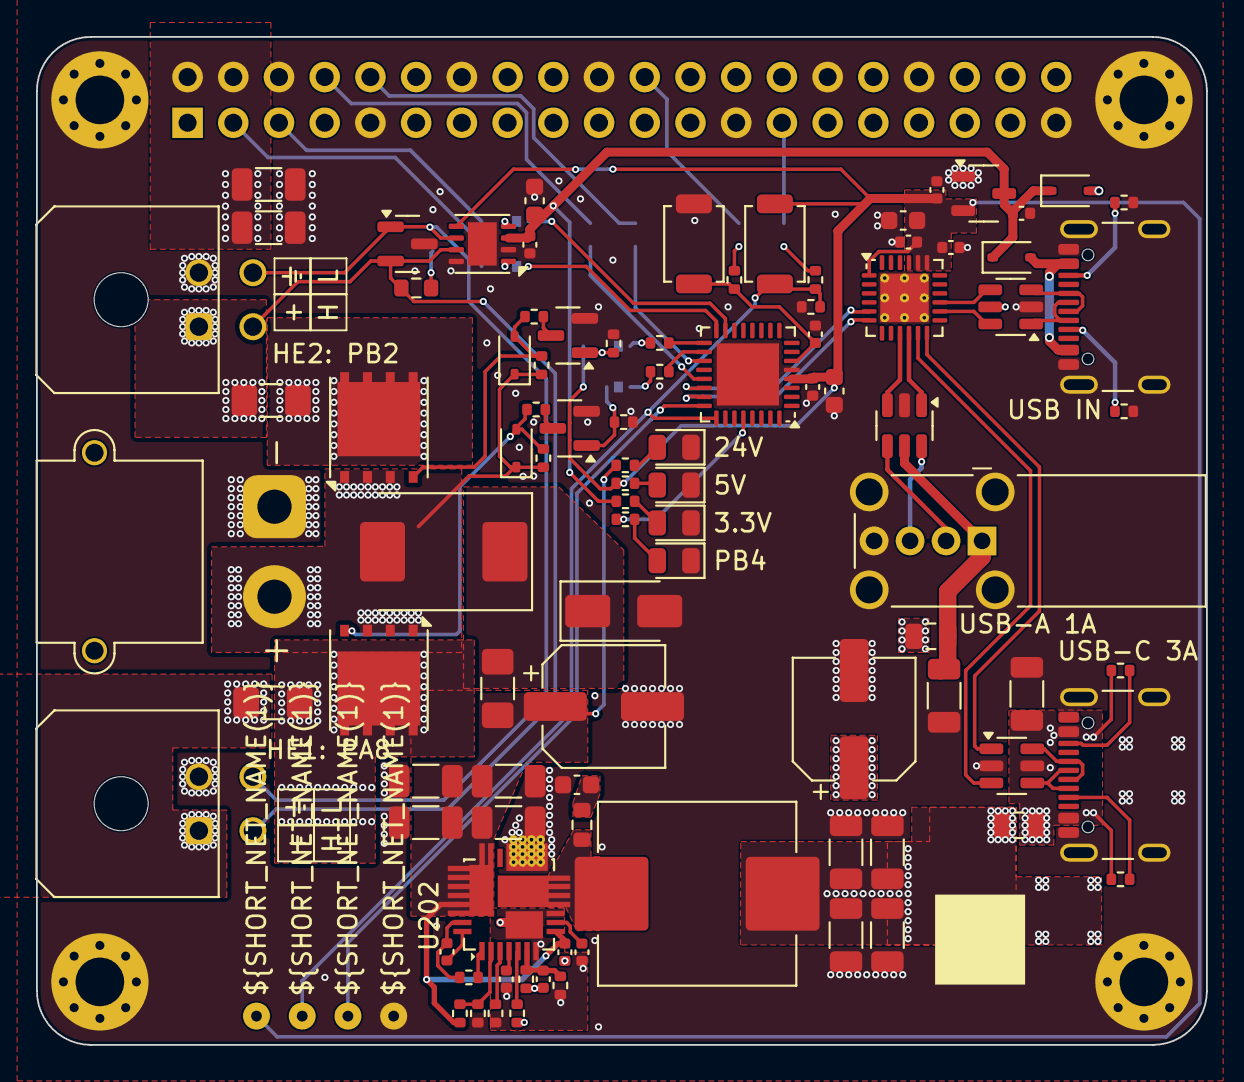
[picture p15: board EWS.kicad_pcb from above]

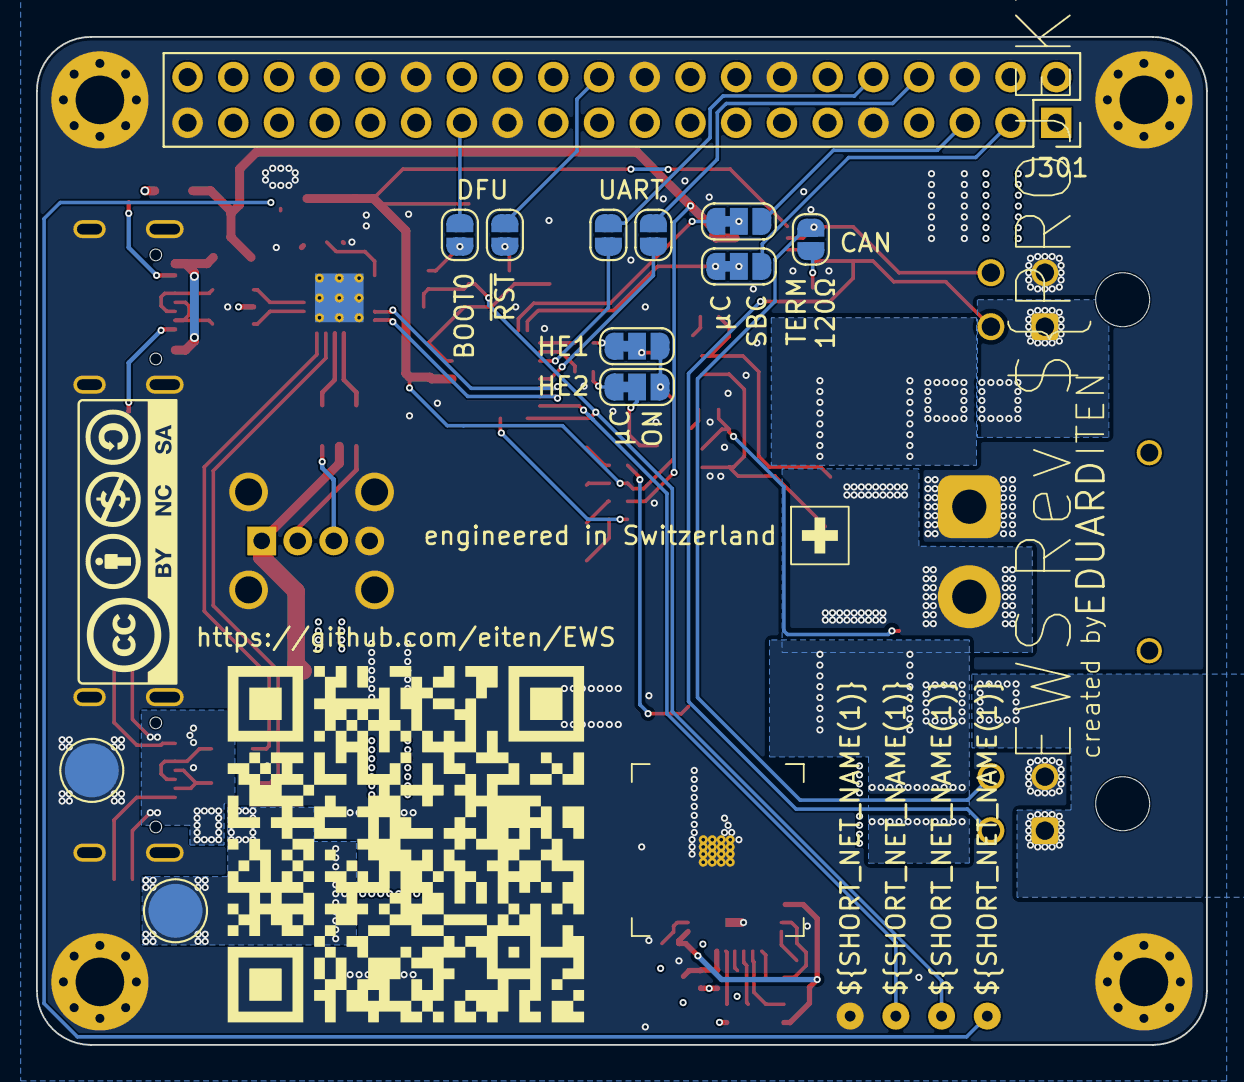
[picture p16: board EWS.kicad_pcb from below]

Board: 4 copper layers, 65.0 x 56.0 mm, 122 parts (18 on the bottom side), 79 nets.

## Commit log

2025-12-03 Add comprehensive installation documentation
    - Created bilingual installation guides (German/English)
    - Added detailed kernel driver diagnosis procedures
    - Included step-by-step Device Tree Overlay setup
    - Enhanced troubleshooting for Rock OS CAN support
    - Updated README files with latest specifications
    - Removed obsolete CSV export file
    [EWS.csv]
2025-12-03 Major hardware update: toolhead switching, DC/DC protection, and documentation overhaul
    Hardware Changes:
    - Replaced reverse polarity protection with 2x PFET toolhead switching (PB2/PA5 control)
    - Added SS56 Schottky diode reverse polarity protection for DC/DC converter
    - Updated current limit resistor to 5.1kΩ (~10.2A)
    - Removed fan control circuitry and JST-XH connector
    - Removed internal JST-XH USB port with fuse/protection
    Documentation Updates:
    - Updated both README files to reflect hardware changes
    - Removed all fan control references and configurations
    - Updated Klipper configuration examples
    - Cleaned up pinout and connector assignments
    - Updated technical specifications table
    - Fi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
    [EWS.kicad_pcb, EWS.kicad_sch, bom.csv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]
2025-12-03 Update schema files: conn.kicad_sch and power.kicad_sch
    - Updated connector schematic (conn.kicad_sch)
    - Updated power schematic (power.kicad_sch)
    - Schema changes reflect latest hardware modifications
    [conn.kicad_sch, power.kicad_sch]
2025-12-04 Enhanced documentation and final hardware corrections
    Documentation Improvements:
    - Added comprehensive 'Problems Addressed' section explaining the value proposition
    - Covers power supply issues, CAN communication problems, safety concerns, and wiring challenges
    - Removed JST-XH internal USB port references from pinout sections
    - Corrected via placement specification (DC/DC PGND instead of output)
    Hardware Updates:
    - Updated schema files with latest component changes
    - Added custom footprints for XR76203ELTR-F and heat sink components
    - Refined manufacturing guidelines for optimal thermal performance
    The documentation now clearly articulates the EWS board's role in solving common
    Voron 3D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
    [9x9x5.step, EWS.kicad_pcb, EWS.kicad_sch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]
2025-12-04 Updated schematics
2025-12-04 EWS Rev 0.1 - Complete design with documentation
    Release Features:
    - Universal HAT for Raspberry Pi 4/5 and Radxa Rock 5B/5B+
    - 8A DC/DC converter with SS56 reverse polarity protection
    - Dual toolhead switching via PFETs (PB2/PA5 control)
    - Native CAN and USB-CAN bridge support
    - USB hub with power delivery for touchscreens
    - Comprehensive safety features and thermal management
    Hardware:
    - STM32G0B1KBU6 MCU with crystal-less design
    - MaxLinear XR76208 switching regulator
    - MCP2542WFD CAN transceiver with jumper selection
    - WCH CH334F USB hub with MTT support
    - 2oz copper PCB recommended for thermal performance
    Documentation:
    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
    [EWS.kicad_pcb, conn.kicad_sch, mcu.kicad_sch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]
2025-12-08 Rev 0.2: Major hardware improvements and production readiness
    Hardware Improvements (Thanks to shx for schematic cleanup):
    - Clean up schematic organization and structure
    - Set CAN transceiver Silent pin to GND for stability
    - Add status LEDs (yellow: 24V/5V/3.3V, green: MCU PB4)
    - Replace jumpers with solder jumpers on bottom side
    - Add jumpers to output PFETs for permanent-on without firmware
    - Add robust test points for 5V/GND load testing
    - Add optional heatsink for DC/DC converter on bottom
    - Add 10µF capacitor for MCU on 3.3V rail
    Component Optimizations:
    - Replace 30kΩ with 33kΩ basic part for simplified BOM
    - Change DC/DC feedback: 15.5kΩ15kΩ (new output: 5.1V)
    - Upgrade CAN ES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
    [EWS.kicad_pcb, EWS.kicad_sch, bom.csv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]
2025-12-09 Rev. 0.3: Add 10µF capacitor C304 to CAN transceiver and QR code placeholder
    - Added 10µF capacitor C304 for improved CAN communication stability
    - Added QR code placeholder for serial number on PCB
    - Enhanced signal integrity with additional filtering at CAN transceiver
    - Improved traceability with unique identification capability
    - Updated changelogs and documentation for Rev. 0.3
    [EWS.kicad_pcb, bom.csv, designators.csv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]
2025-12-09 Production Optimization: JLCPCB assembly improvements
    - Excluded test points TP202/TP203 from BOM
    - Set FT rotation offsets for automated assembly:
    - U202/U301: 270° rotation offset
    - U401: 180° rotation offset
    - Updated production data for JLCPCB compatibility
    - Added unreleased changelog section for tracking
    [EWS.kicad_pcb, bom.csv, mcu.kicad_sch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]
